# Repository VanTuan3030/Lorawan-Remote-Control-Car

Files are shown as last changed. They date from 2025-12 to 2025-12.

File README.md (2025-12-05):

# Hand Gesture Controlled Car via LoRaWAN (STM32 + MPU6050)

This project builds a remote-controlled robot car system using **Hand Gesture Control**, powered by **LoRa (Long Range)** wireless communication technology. The system allows for stable vehicle control over long distances with excellent obstacle penetration, significantly outperforming traditional RF or Bluetooth solutions.

## 📡 LoRa Technology - Project Highlight

This is the core feature that sets this project apart. Instead of using standard radio waves, the system utilizes the **LoRa Ra-02 (SX1278)** module operating at **433MHz**.

### Why LoRa?
* **Superior Range:** Capable of transmitting signals from several hundred meters to kilometers (in ideal conditions), solving the signal loss issue when the car travels far away.
* **High Interference Immunity:** Uses **CSS (Chirp Spread Spectrum)** modulation technique, ensuring signals are not attenuated or interfered with by other electronic devices.
* **Obstacle Penetration:** The 433MHz LoRa signal has a long wavelength, allowing for vehicle control even when obstructed by walls or large objects.

### Communication Protocol
The system operates on a **Point-to-Point (P2P)** model:
1.  **Data Acquisition:** The STM32 microcontroller at the Transmitter reads tilt angles (Roll, Pitch) from the MPU6050 sensor.
2.  **Packetizing:** Data is packed into a `Struct` to ensure integrity.
3.  **Modulation & Transmission:** The SX1278 module modulates this packet into LoRa waves and transmits it.
4.  **Decoding & Execution:** The Receiver captures the waves, decodes the packet back into motor control signals.

## 🚀 Key Features

* **Gesture Control:**
    * 👋 **Tilt Forward:** Move Forward.
    * 👋 **Tilt Backward:** Move Backward.
    * 👋 **Tilt Left/Right:** Turn Left/Right.
    * 👋 **Keep Level:** Stop.
* **Real-time Processing:** Ultra-fast response speed thanks to the STM32F103 microcontroller (32-bit ARM Cortex-M3).
* **Powerful & Flexible:** The car uses 4 DC motors with an L298N Driver, enabling versatile multi-directional movement.

## 🛠️ Hardware Requirements

### 1. Transmitter (Handheld)
* **Microcontroller:** STM32F103C8T6 (Blue Pill).
* **Sensor:** MPU6050 (6-axis Accelerometer & Gyroscope).
* **Communication:** LoRa Ra-02 Module (SX1278) + 433MHz Antenna (Spring/External).
* **Power:** 3.7V Li-ion Battery or 9V Battery.

### 2. Receiver (Car)
* **Microcontroller:** STM32F103C8T6 (Blue Pill).
* **Communication:** LoRa Ra-02 Module (SX1278).
* **Motors:** L298N Driver + 4 DC Geared Motors + Robot Chassis.
* **Power:** High-capacity Rechargeable Battery (e.g., 2x 18650 cells in series ~7.4V).

## 🔌 Pinout Diagram

Communication between STM32 and LoRa SX1278 uses the **SPI** standard.

### Transmitter Unit

| Device | STM32 Pin | Function |
| :--- | :--- | :--- |
| **LoRa Ra-02 (NSS)** | PA4 | Chip Select (CS) |
| **LoRa Ra-02 (SCK)** | PA5 | SPI Clock |
| **LoRa Ra-02 (MISO)**| PA6 | SPI Data In |
| **LoRa Ra-02 (MOSI)**| PA7 | SPI Data Out |
| **LoRa Ra-02 (RST)** | PB0 | Reset |
| **LoRa Ra-02 (DIO0)**| PB1 | Interrupt (Tx Done) |
| **MPU6050 (SCL)** | PB6 | I2C Clock |
| **MPU6050 (SDA)** | PB7 | I2C Data |

### Receiver Unit

| Device | STM32 Pin | Function |
| :--- | :--- | :--- |
| **LoRa Ra-02** | PA4, PA5, PA6, PA7 | SPI Connection (Same as Transmitter) |
| **L298N (IN1)** | PA0 | Left Motor (+) |
| **L298N (IN2)** | PA1 | Left Motor (-) |
| **L298N (IN3)** | PA2 | Right Motor (+) |
| **L298N (IN4)** | PA3 | Right Motor (-) |

## 💻 Installation and Usage

1.  **Software & Libraries:**
    * IDE: **Keil C V5** or **STM32CubeIDE**.
    * Configuration: **STM32CubeMX** (Configure SPI for LoRa, I2C for MPU6050).
    * Libraries: Import driver libraries for `SX1278` and `MPU6050`.

2.  **Flashing Firmware:**
    * Connect the ST-Link V2 programmer.
    * Upload `Transmitter.hex` code to the handheld circuit.
    * Upload `Receiver.hex` code to the car circuit.

3.  **Operation:**
    * Turn on the car power first, then the handheld controller.
    * Wait 1-2 seconds for the LoRa modules to initialize and synchronize frequencies.
    * Tilt your hand and observe the car's movement.

## 👤 Authors

* **Student Team:** Vo Van Tuan - 6251020094
* **Instructor:** Dr. Le Tien Loc
* **Class:** Industrial Electronics & Informatics K62
* **University:** University of Transport and Communications - HCMC Campus

---
*Project for the Course Final Report - IoT & LoRa Applications.*

https://github.com/user-attachments/assets/69dc1bef-388b-4bd6-928f-9bf30ec7da8c

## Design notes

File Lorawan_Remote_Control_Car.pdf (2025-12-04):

TRƯỜNG ĐẠI HỌC GIAO THÔNG VẬN TẢI

PHÂN HIỆU TẠI THÀNH PHỐ HỒ CHÍ MINH

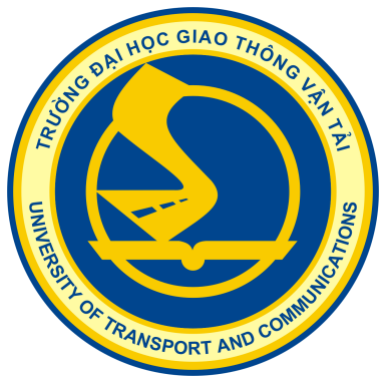
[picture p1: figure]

### BÁO CÁO TỔNG KẾT

## ĐIỀU KHIỂN XE BẰNG MPU6050 THÔNG QUA

## LORA

Sinh viên thực hiện | Ngô Huỳnh Quốc Huy | Mssv: 6251020057
| Võ Văn Tuấn | Mssv: 6251020094
| Hà Nhật Chương | Mssv: 6251020037

Lớp: Điện tử tin học công nghiệp K62

Người hướng dẫn: TS. Lê Tiến Lộc

TPHCM, 2025

TRƯỜNG ĐẠI HỌC GIAO THÔNG VẬN TẢI

PHÂN HIỆU TẠI THÀNH PHỐ HỒ CHÍ MINH

### BÁO CÁO TỔNG KẾT

## ĐIỀU KHIỂN XE BẰNG MPU6050 THÔNG QUA

## LORA

Sinh viên thực hiện | Ngô Huỳnh Quốc Huy | Mssv: 6251020057
| Võ Văn Tuấn | Mssv: 6251020094
| Hà Nhật Chương | Mssv: 6251020037

Lớp: Điện tử tin học công nghiệp K62

Người hướng dẫn: TS. Lê Tiến Lộc

TPHCM, 2025

MỤC LỤC

DANH MỤC HÌNH ẢNH

DANH MỤC BẢNG

KÍ TỰ VIẾT TẮT

Viết tắt | Diễn giải
ADC | Analog to Digital Converter (Bộ chuyển đổi tương tự – số)
DOF | Degree of Freedom (Bậc tự do)
DMP | Digital Motion Processor (Bộ xử lý chuyển động số)
HAL | Hardware Abstraction Layer (Lớp trừu tượng phần cứng)
I2C | Inter-Integrated Circuit (Chuẩn giao tiếp nối tiếp)
LoRa | Long Range (Công nghệ truyền thông tầm xa)
MPU6050 | Tên cảm biến tích hợp gia tốc kế & con quay hồi chuyển
NSS | Network Select Slave (Chân chọn chip trong giao tiếp SPI)
PWM | Pulse Width Modulation (Điều chế độ rộng xung)
SPI | Serial Peripheral Interface (Giao tiếp ngoại vi nối tiếp)
STM32 | Dòng vi điều khiển 32-bit của STMicroelectronics
UART | Universal Asynchronous Receiver Transmitter (Truyền nhận không đồng bộ phổ thông)

CHƯƠNG 1: GIỚI THIỆU ĐỀ TÀI

1.1. Lý do chọn đề tài.

Nhu cầu thị trường:

Hiện nay, các hệ thống điều khiển phương tiện, robot hoặc thiết bị từ xa phần lớn vẫn sử dụng tay điều khiển (remote) hoặc điện thoại thông minh kết nối qua Bluetooth hoặc WiFi. Tuy nhiên, các công nghệ này có phạm vi hoạt động hạn chế và dễ bị ảnh hưởng bởi vật cản, tín hiệu nhiễu hoặc mất kết nối trong môi trường rộng lớn, đặc biệt ở các khu vực không có mạng internet ổn định. Điều này gây ra nhiều bất tiện cho người sử dụng cũng như hạn chế khả năng mở rộng ứng dụng trong thực tế.

Tiềm năng ứng dụng rộng rãi:

Việc điều khiển thiết bị từ xa bằng cách sử dụng cảm biến chuyển động (MPU6050) kết hợp với công nghệ truyền thông tầm xa LoRa mở ra hướng ứng dụng rộng rãi cho nhiều lĩnh vực như: xe điều khiển trong nông nghiệp, robot cứu hộ, xe tự hành, hoặc các thiết bị vận chuyển trong nhà kho, nhà máy. Giải pháp này cho phép người dùng điều khiển thiết bị một cách trực quan bằng các cử chỉ tay mà không cần dây dẫn hay mạng internet, đồng thời duy trì kết nối ổn định ở khoảng cách xa.

Ứng dụng công nghệ tiên tiến:

Đề tài ứng dụng cảm biến MPU6050 – một module tích hợp con quay hồi chuyển và gia tốc kế – để nhận biết chuyển động của tay người điều khiển. Dữ liệu từ cảm biến sẽ được xử lý và truyền không dây bằng công nghệ LoRa, vốn nổi bật với khả năng truyền xa (lên đến hàng km) và tiêu thụ năng lượng thấp. Hệ thống có thể hoạt động hiệu quả trong môi trường mở, độc lập với hạ tầng mạng hiện có, đồng thời dễ dàng triển khai thực tế.

Chi phí triển khai hợp lý:

Các module MPU6050 và LoRa hiện nay có giá thành thấp, phổ biến trên thị trường và dễ tiếp cận đối với sinh viên, kỹ sư hoặc cá nhân nghiên cứu độc lập. Điều này cho phép triển khai hệ thống điều khiển thông minh với chi phí thấp hơn nhiều so với các giải pháp thương mại, đồng thời dễ dàng mở rộng và tùy chỉnh theo nhu cầu sử dụng. Đề tài mang lại một lựa chọn tiết kiệm, linh hoạt và phù hợp với xu hướng phát triển thiết bị điều khiển không dây hiện đại.

### 1.2. Mục tiêu đề tài

Xây dựng hệ thống điều khiển xe từ xa bằng cử chỉ tay thông qua cảm biến MPU6050, truyền tín hiệu không dây bằng công nghệ LoRa với chi phí thấp, dễ triển khai và không phụ thuộc vào mạng internet.

Nhận diện chính xác chuyển động tay (nghiêng, xoay) để điều khiển các hướng di chuyển của xe (tiến, lùi, trái, phải), đảm bảo độ nhạy và độ trễ thấp trong quá trình điều khiển thực tế.

Tăng tính linh hoạt và tự động hóa, giúp người dùng điều khiển xe từ khoảng cách xa (lên đến vài trăm mét đến vài km trong điều kiện lý tưởng), phù hợp cho các ứng dụng trong nông nghiệp, môi trường đặc biệt hoặc robot địa hình.

CHƯƠNG 2: CƠ SỞ LÝ THUYẾT

### 2.1. Khái niệm về hệ thống nhúng

Hệ thống nhúng (embedded system) là một thuật ngữ để chỉ một hệ thống có khả năng tự trị được nhúng vào trong một môi trường hay hệ thống mẹ. Đó là các hệ thống tích hợp cả phần cứng và phần mềm phục vụ các bài toán chuyên dụng trong nhiều lĩnh vực công nghiệp, tự động hoá điều khiển, quan trắc và truyền tin. Đặc điểm của các hệ thống nhúng là hoạt động ổn định và có tính năng tự động hoá cao.

Hệ thống nhúng thường được thiết kế để thực hiện một chức năng chuyên biệt nào đó. Khác với các máy tính (https://vi.wikipedia.org/wiki/M%C3%A1y_t%C3%ADnh) đa chức năng, chẳng hạn như máy tính cá nhân, (https://vi.wikipedia.org/wiki/M%C3%A1y_t%C3%ADnh_c%C3%A1_nh%C3%A2n) một hệ thống nhúng chỉ thực hiện một hoặc một vài chức năng nhất định, thường đi kèm với những yêu cầu cụ thể và bao gồm một số thiết bị máy móc và phần cứng chuyên dụng mà ta không tìm thấy trong một máy tính đa năng nói chung. Vì hệ thống chỉ được xây dựng cho một số nhiệm vụ nhất định nên các nhà thiết kế có thể tối ưu hóa nó nhằm giảm thiểu kích thước và chi phí sản xuất. Các hệ thống nhúng thường được sản xuất hàng loạt với số lượng lớn. Hệ thống nhúng rất đa dạng, phong phú về chủng loại. Đó có thể là những thiết bị cầm tay nhỏ gọn như đồng hồ kĩ thuật số và máy chơi nhạc MP3, hoặc những sản phẩm lớn như đèn giao thông, bộ kiểm soát trong nhà máy hoặc hệ thống kiểm soát các máy năng lượng hạt nhân. Xét về độ phức tạp, hệ thống nhúng có thể rất đơn giản với một vi điều khiển (https://vi.wikipedia.org/wiki/Vi_%C4%91i%E1%BB%81u_khi%E1%BB%83n) hoặc rất phức tạp với nhiều đơn vị, các thiết bị ngoại vi và mạng lưới được nằm gọn trong một lớp vỏ máy lớn.

Các thiết bị PDA hoặc máy tính cầm tay cũng có một số đặc điểm tương tự với hệ thống nhúng như các hệ điều hành hoặc vi xử lý điều khiển chúng nhưng các thiết bị này không phải là hệ thống nhúng thật sự bởi chúng là các thiết bị đa năng, cho phép sử dụng nhiều ứng dụng và kết nối đến nhiều thiết bị ngoại vi.

Bên cạnh đó, xu hướng hiện nay đang hướng đến việc phát triển các hệ thống nhúng thông minh, có khả năng kết nối Internet (IoT – Internet of Things) và xử lý dữ liệu ngay tại thiết bị mà không cần phụ thuộc vào máy chủ trung tâm. Việc tích hợp trí tuệ nhân tạo (AI) vào hệ thống nhúng cũng đang được nghiên cứu và ứng dụng mạnh mẽ, mở ra nhiều tiềm năng mới trong lĩnh vực tự động hóa và điều khiển thông minh.

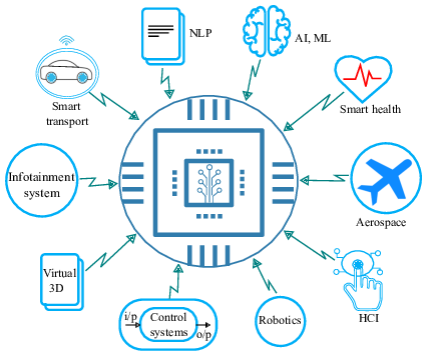
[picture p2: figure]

Hình 2.1: Hệ thống nhúng

### 2.2. Tín hiệu cảm biến và xử lý tín hiệu

Trong một hệ thống đo lường, cảm biến là thành phần đầu vào có nhiệm vụ chuyển đổi các đại lượng vật lý cần đo (chẳng hạn như chuyển động, áp suất, nhiệt độ, ánh sáng, từ trường…) thành tín hiệu điện. Đây là bước quan trọng đầu tiên để biến thông tin thực tế thành dữ liệu có thể phân tích và xử lý trong môi trường số.

Tín hiệu do cảm biến tạo ra thường thuộc một trong hai dạng chính:

Tín hiệu tương tự (analog): Là tín hiệu biến thiên liên tục theo thời gian, biểu hiện qua điện áp hoặc dòng điện thay đổi theo giá trị đo được. Loại tín hiệu này yêu cầu sử dụng bộ chuyển đổi tương tự – số (ADC) để đưa vào xử lý trên hệ thống vi điều khiển.

Tín hiệu số (digital): Là tín hiệu có dạng rời rạc, thường biểu diễn bằng hai mức logic (cao/thấp, 1/0). Loại tín hiệu này có thể được đọc trực tiếp bởi các chân vào số của vi điều khiển, và được xử lý dễ dàng hơn so với tín hiệu tương tự.

Việc xử lý tín hiệu cảm biến trong hệ thống đo lường thường bao gồm các bước:

Xử lý: Bao gồm khuếch đại tín hiệu yếu, lọc nhiễu điện, ổn định mức tín hiệu đầu vào.

Chuyển đổi tín hiệu: Nếu là tín hiệu analog thì cần chuyển đổi sang dạng số; nếu là tín hiệu số thì có thể đọc và xử lý trực tiếp.

Trích xuất thông tin: Là bước phân tích dữ liệu nhận được để rút ra giá trị đo có ý nghĩa, như tốc độ, vị trí...

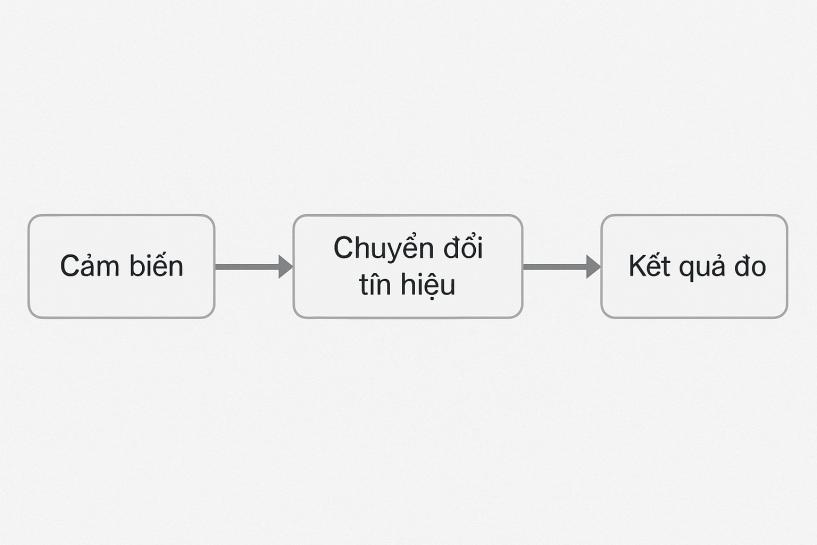
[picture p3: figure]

Hình 2.2: Mô hình cảm biến

### 2.3. Tổng quan về hệ thống nhúng trong đo lường

Một hệ thống đo lường sử dụng nền tảng hệ nhúng thường hoạt động theo một chu trình khép kín và liên tục, đảm bảo thu thập và xử lý dữ liệu một cách hiệu quả và đáng tin cậy. Quy trình cơ bản có thể mô tả qua các bước sau:

Giai đoạn thu nhận dữ liệu đầu vào: Các cảm biến chuyên dụng sẽ ghi nhận các đại lượng vật lý như chuyển động, áp suất, ánh sáng, nhiệt độ, độ ẩm, tốc độ dòng chảy,... tùy theo yêu cầu của ứng dụng. Mỗi loại cảm biến thường cho ra tín hiệu điện áp, dòng điện hoặc xung số tương ứng với giá trị của đại lượng đo được.

Giai đoạn chuyển đổi và đưa vào hệ thống: Tín hiệu đầu ra của cảm biến sẽ được đưa vào hệ thống nhúng thông qua các chân analog hoặc digital trên vi điều khiển. Trường hợp tín hiệu là analog, hệ thống sẽ sử dụng bộ chuyển đổi ADC (Analog to Digital Converter) để biến đổi thành tín hiệu số phục vụ cho xử lý.

Xử lý tín hiệu và tính toán: Vi điều khiển trong hệ thống nhúng sẽ nhận dữ liệu và thực hiện các thuật toán xử lý: lọc nhiễu, tính trung bình, phân tích ngưỡng, hoặc các thuật toán điều khiển như PID. Đây là khâu quan trọng giúp đảm bảo kết quả đo chính xác, ổn định và phù hợp với yêu cầu thực tế.

Giai đoạn xuất dữ liệu: Sau khi xử lý, kết quả có thể được hiển thị trực tiếp trên màn hình LCD/OLED, hoặc được gửi đi thông qua giao tiếp UART, I2C, SPI hoặc Wi-Fi/Bluetooth. Ngoài ra, hệ thống cũng có thể ghi log vào bộ nhớ trong, thẻ SD hoặc gửi lên server/cloud/Firebase để lưu trữ và phân tích từ xa.

Tổng quát, mô hình hoạt động có thể biểu diễn như sau:

Cảm biến → Vi điều khiển → Xử lý tín hiệu → Hiển thị / Giao tiếp / Lưu trữ

Trong các ứng dụng hiện đại, hệ thống nhúng còn có thể mở rộng thêm các chức năng như gửi cảnh báo khi vượt ngưỡng, kích hoạt relay điều khiển thiết bị, hoặc đồng bộ dữ liệu thời gian thực với hệ thống giám sát trung tâm. Điều này giúp hệ nhúng không chỉ là công cụ đo lường đơn thuần mà còn đóng vai trò như một phần tử quyết định trong hệ thống điều khiển tự động và thông minh hóa quy trình.

CHƯƠNG 3: GIỚI THIỆU LINH KIỆN SỬ DỤNG

### 3.1. Vi điều khiển STM32F103C8T6

### 3.1.1. Giới thiệu chung

STM32F103C8T6 là vi điều khiển thuộc dòng STM32 của STMicroelectronics, sử dụng lõi ARM Cortex-M3 với tốc độ xử lý lên đến 72 MHz. Đây là một trong những dòng vi điều khiển phổ biến nhờ khả năng xử lý mạnh, tiêu thụ năng lượng thấp, giá thành rẻ và được hỗ trợ bởi cộng đồng phát triển rộng lớn.

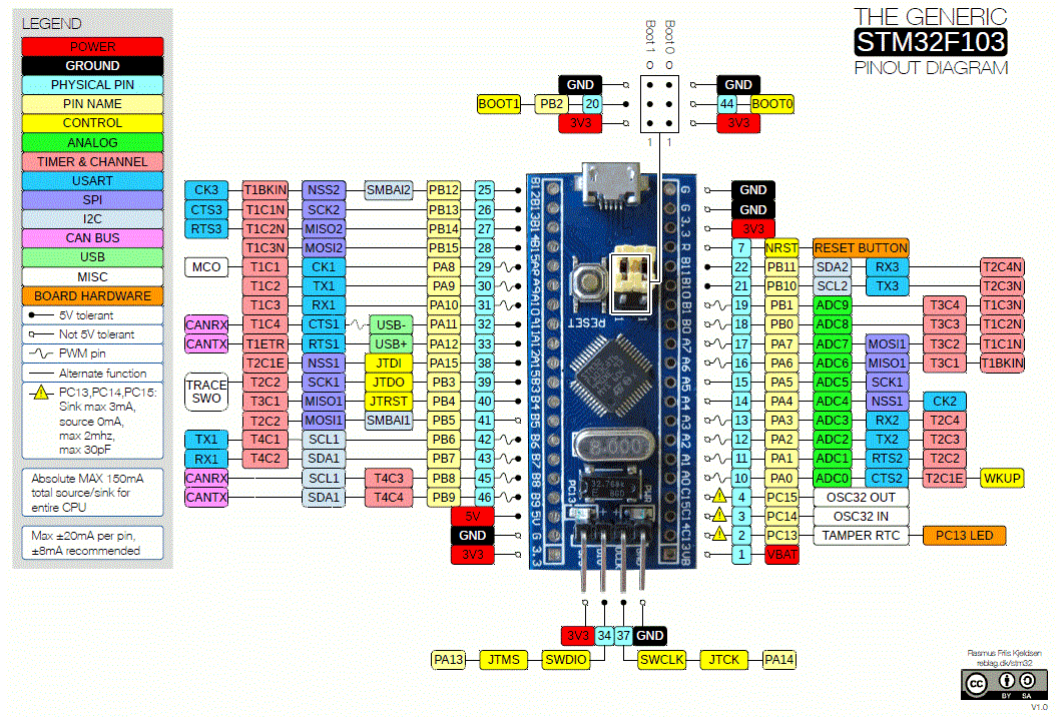
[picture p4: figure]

Hinh 3.1: tổng quan stm32f103c8

### 3.1.2. Thông số kỹ thuật chính

Lõi xử lý: ARM Cortex-M3, 32-bit, 72 MHz

Bộ nhớ: 64 KB Flash, 20 KB SRAM

Số chân I/O: 37 (đa chức năng)

Giao tiếp: UART, I2C, SPI, PWM, ADC,...

Điện áp hoạt động: 2.0V – 3.6V

Tích hợp đồng hồ RTC, bộ định thời (Timer), Watchdog,...

### 3.1.3. Vai trò trong hệ thống

STM32F103C8T6 là bộ vi điều khiển lõi ARM Cortex-M3 được thiết kế để đáp ứng các yêu cầu xử lý đa nhiệm trong các ứng dụng nhúng. Với tốc độ xử lý lên đến 72 MHz cùng bộ ngoại vi phong phú như UART, SPI, I2C, ADC, PWM,... STM32 cho phép kết nối với nhiều loại cảm biến và module truyền thông. Ngoài ra, nó hỗ trợ chế độ tiết kiệm năng lượng và khả năng xử lý ngắt linh hoạt, rất phù hợp cho các hệ thống yêu cầu phản hồi nhanh và ổn định.

Trong hệ thống điều khiển xe bằng cử chỉ, STM32F103C8 đóng vai trò là trung tâm xử lý chính:

Giao tiếp với cảm biến MPU6050 thông qua giao thức I2C để thu thập dữ liệu chuyển động (góc nghiêng, vận tốc quay).

Xử lý tín hiệu cảm biến, áp dụng các thuật toán lọc (như low-pass filter, Kalman filter) để loại bỏ nhiễu và ổn định dữ liệu đầu vào.

Phân tích dữ liệu chuyển động để xác định hành động điều khiển tương ứng (ví dụ: nghiêng tay về phía trước tương ứng với lệnh "tiến").

Truyền lệnh điều khiển sang module LoRa, sử dụng giao thức SPI, để gửi dữ liệu không dây đến phần nhận tín hiệu trên xe.

Nhờ khả năng xử lý nhanh, hoạt động ổn định và tài nguyên phần cứng đa dạng, STM32 là lựa chọn lý tưởng cho các hệ thống điều khiển thực thời có yêu cầu về độ tin cậy và độ trễ thấp.

### 3.2. Cảm biến MPU6050

### 3.2.1. Giới thiệu chung

MPU6050 là cảm biến tích hợp 3 trục gia tốc kế và 3 trục con quay hồi chuyển, cho phép đo được gia tốc tuyến tính và tốc độ quay quanh các trục XYZ. Module này rất phổ biến trong các ứng dụng nhận dạng chuyển động, cân bằng robot, điều khiển bằng cử chỉ...

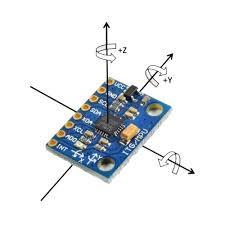
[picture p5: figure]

Hinh 3.2: tổng quan mpu6050

### 3.2.2. Thông số kỹ thuật chính

Gia tốc kế: ±2g, ±4g, ±8g, ±16g

Con quay hồi chuyển: ±250, ±500, ±1000, ±2000°/s

Giao tiếp: I2C (địa chỉ mặc định 0x68)

Tích hợp DMP (Digital Motion Processor)

Điện áp hoạt động: 3.3V – 5V

### 3.2.3. Vai trò trong hệ thống

MPU6050 là cảm biến tích hợp 6 bậc tự do (6 DOF), bao gồm:

Gia tốc kế 3 trục (Accelerometer): đo gia tốc tuyến tính dọc theo các trục X, Y, Z (đơn vị: m/s² hoặc g).

Con quay hồi chuyển 3 trục (Gyroscope): đo tốc độ quay quanh các trục X, Y, Z (đơn vị: độ/giây).

MPU6050 có thể kết hợp dữ liệu từ cả hai loại cảm biến để tính toán góc nghiêng (pitch, roll, yaw) của thiết bị. Với khả năng giao tiếp qua I2C, cảm biến dễ dàng kết nối với các vi điều khiển để truyền dữ liệu thời gian thực.

Trong đề tài này, MPU6050 được gắn vào tay người điều khiển. Dựa trên dữ liệu từ cảm biến:

Khi người dùng nghiêng tay theo hướng nhất định, hệ thống sẽ ghi nhận được sự thay đổi góc nghiêng hoặc vận tốc quay.

Dữ liệu này được phân tích để xác định hành vi điều khiển: nghiêng trái → rẽ trái, nghiêng phải → rẽ phải, nghiêng về trước → đi tới, nghiêng lùi → đi lui.

MPU6050 đóng vai trò như một bộ điều khiển chuyển động tự nhiên, thay thế cho các thiết bị điều khiển truyền thống như joystick hay nút bấm.

Tuy nhiên, do đặc điểm nhạy cảm với dao động nhỏ và nhiễu từ môi trường, cần phải có bộ lọc tín hiệu và hiệu chỉnh trong phần mềm để đảm bảo tính ổn định và chính xác của tín hiệu điều khiển.

### 3.3. Module truyền thông LoRa

### 3.3.1. Giới thiệu chung

LoRa là công nghệ truyền thông không dây tầm xa, tiêu thụ năng lượng thấp, sử dụng kỹ thuật điều chế LoRa (Long Range). Module Ra-02 hoặc SX1278 là một trong những phiên bản phổ biến, hoạt động ở tần số 433 MHz hoặc 868/915 MHz tùy theo khu vực.

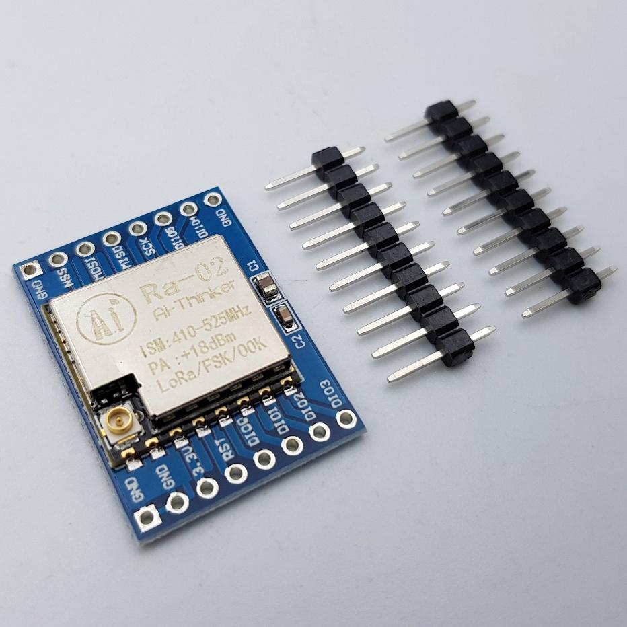
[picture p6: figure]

Hinh 3.3: tổng quan lora

### 3.3.2. Thông số kỹ thuật chính

Tần số hoạt động: 433 MHz (hoặc 868/915 MHz)

Khoảng cách truyền: lên đến 2–5 km (môi trường mở)

Giao tiếp: SPI

Công suất phát: +20 dBm

Tốc độ truyền: 0.018 – 37.5 kbps

Điện áp: 1.8V – 3.7V (thường dùng 3.3V)

### 3.3.3. Vai trò trong hệ thống

LoRa (Long Range) là công nghệ truyền thông không dây sử dụng kỹ thuật điều chế dải tần rộng (spread spectrum modulation), giúp truyền tín hiệu ở khoảng cách xa với công suất thấp. LoRa hoạt động tốt trong môi trường có vật cản hoặc khu vực nông thôn – nơi tín hiệu WiFi hoặc Bluetooth thường bị hạn chế.

Các module như Ra-02 hoặc SX1278 sử dụng giao thức SPI để giao tiếp với vi điều khiển, có khả năng truyền dữ liệu với khoảng cách lên đến 2–5 km trong điều kiện lý tưởng.

Trong hệ thống điều khiển xe:

LoRa được sử dụng để truyền tín hiệu điều khiển từ bộ tay cầm (người điều khiển) đến xe. Tín hiệu này chứa thông tin đã được xử lý từ MPU6050, như hướng di chuyển và trạng thái hành động.

Nhờ khả năng truyền xa và chống nhiễu tốt, LoRa cho phép người dùng điều khiển xe ở khoảng cách lớn mà không cần đến mạng internet.

Hệ thống hoạt động ở tần số 433 MHz hoặc 868 MHz, với tốc độ truyền vừa phải nhưng ổn định và tiết kiệm năng lượng, phù hợp với các ứng dụng điều khiển đơn giản nhưng yêu cầu truyền xa và đáng tin cậy.

LoRa không thích hợp cho truyền dữ liệu lớn, nhưng rất phù hợp trong ứng dụng điều khiển như đề tài này, nơi chỉ cần gửi các gói dữ liệu nhỏ nhưng thường xuyên và ổn định.

CHƯƠNG 4: THIẾT KẾ HỆ THỐNG ĐIỀU KHIỂN

4.1, kiến trúc tổng thể của hệ thống

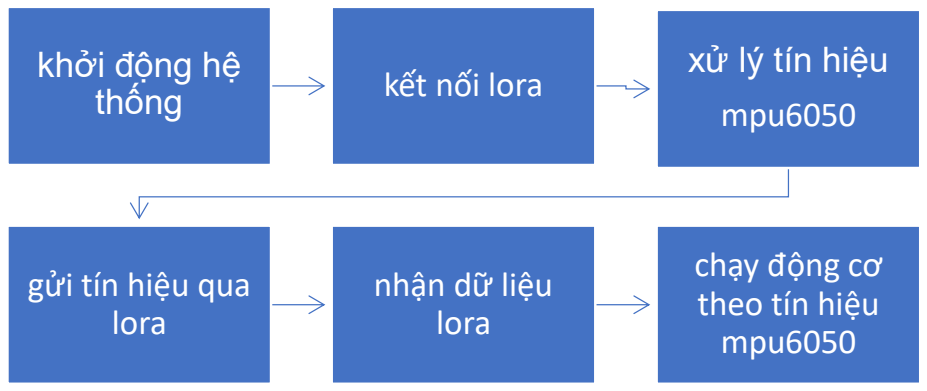
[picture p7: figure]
khởi động hệ; thống; kết nối lora; xử lý tín hiệu; mpu6050; gửi tín hiệu qua lora; nhận dữ liệu lora; chạy động cơ theo tín hiệu mpu6050

Bảng 4.1 lưu đồ thuật toán

Khởi động hệ thống

Hệ thống bắt đầu hoạt động khi được cấp nguồn. Vi điều khiển (STM32F103C8) tiến hành khởi tạo các thành phần phần cứng: cảm biến MPU6050, module LoRa, các chân I/O.

Kết nối LoRa

Hai module LoRa (phát và thu) được cấu hình để sẵn sàng truyền và nhận dữ liệu. Đây là bước thiết lập thông số truyền (tần số, địa chỉ, tốc độ baud...) giữa hai bên.

Xử lý tín hiệu MPU6050

Cảm biến MPU6050 gửi dữ liệu thô (góc nghiêng, gia tốc, tốc độ quay) đến vi điều khiển thông qua giao tiếp I2C. STM32 xử lý dữ liệu này (lọc nhiễu, phân tích) để xác định hướng điều khiển tương ứng (tiến, lùi, rẽ trái, rẽ phải...).

Gửi tín hiệu qua LoRa

STM32 mã hóa thông tin điều khiển (dưới dạng gói lệnh) và gửi qua module LoRa để truyền không dây đến mạch thu gắn trên xe.

Nhận dữ liệu LoRa

Mạch thu nhận gói dữ liệu từ mạch phát thông qua module LoRa. Dữ liệu sau đó được gửi đến STM32 để xử lý tiếp.

Chạy động cơ theo tín hiệu MPU6050

STM32 ở mạch thu sẽ dịch gói lệnh điều khiển thành tín hiệu logic điều khiển module L298 để quay động cơ theo yêu cầu. Xe sẽ di chuyển đúng với hướng tay người điều khiển.

4.2, Phần cứng hệ thống phát

4.2.1.Sơ đồ mạch điện

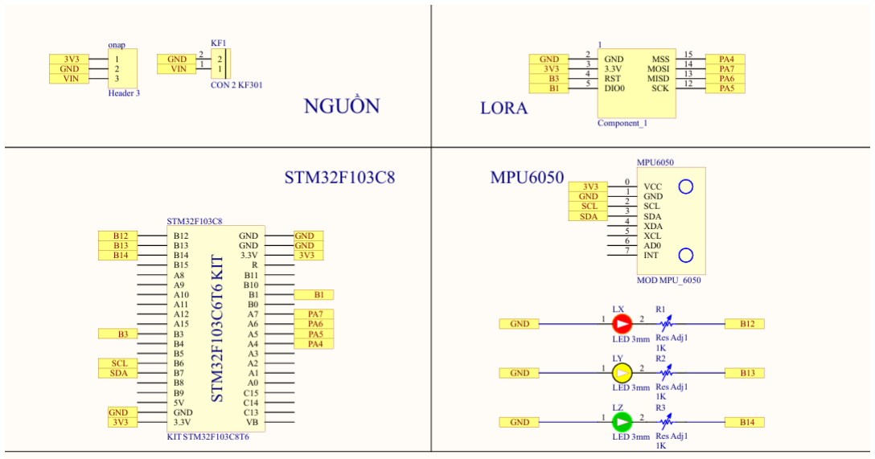
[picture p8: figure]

Hinh 4.1: sơ đồ mạch phát

Mạch phát là phần trung tâm trong hệ thống điều khiển xe từ xa bằng cử chỉ tay. Mạch này được gắn lên tay người dùng và có nhiệm vụ thu nhận chuyển động từ cảm biến MPU6050, xử lý dữ liệu qua vi điều khiển STM32F103C8, sau đó truyền tín hiệu điều khiển đến mạch thu trên xe thông qua module LoRa. Toàn bộ hệ thống được cấp nguồn bằng điện áp 3.3V từ bộ nguồn ngoài.

### 4.2.1.1. Khối nguồn

Khối nguồn có nhiệm vụ cung cấp điện áp ổn định 3.3V cho toàn bộ hệ thống. Nguồn được cấp qua jack CON2 KF301 với hai đầu vào: VIN và GND. Điện áp được điều chỉnh phù hợp cho các linh kiện như STM32, MPU6050 và module LoRa. Khối này đảm bảo hệ thống hoạt động ổn định và an toàn về điện.

### 4.2.1.2. Vi điều khiển STM32F103C8

Vi điều khiển STM32F103C8 đóng vai trò là bộ xử lý trung tâm của hệ thống mạch phát. Nó đảm nhiệm các chức năng sau:

Giao tiếp với cảm biến MPU6050 thông qua chuẩn I2C (chân PB6 – SCL và PB7 – SDA).

Giao tiếp với module LoRa thông qua chuẩn SPI (chân PA4 đến PA7).

Phân tích dữ liệu chuyển động, nhận biết cử chỉ tay điều khiển và chuyển đổi thành tín hiệu điều khiển cụ thể cho xe.

Xuất tín hiệu điều khiển LED thông báo trạng thái chuyển động qua các chân PB12, PB13, PB14 (ứng với trục X, Y, Z).

Vi điều khiển được cấp nguồn 3.3V và có các chân GND được nối về mass chung, đảm bảo tính ổn định cho toàn hệ thống.

### 4.2.1.3. Cảm biến MPU6050

Cảm biến MPU6050 có chức năng ghi nhận dữ liệu chuyển động tay người điều khiển. Cảm biến tích hợp gia tốc kế 3 trục và con quay hồi chuyển 3 trục, cho phép đo được góc nghiêng và tốc độ xoay của tay theo thời gian thực.

Trong mạch phát, MPU6050 được kết nối với STM32 thông qua giao tiếp I2C:

SCL nối với chân PB6.

SDA nối với chân PB7.

Nguồn 3.3V cấp vào chân VCC và GND của cảm biến. Dữ liệu chuyển động thu được từ MPU6050 sẽ được vi điều khiển xử lý để tạo ra lệnh điều khiển thích hợp cho xe.

### 4.2.1.4. Module truyền thông LoRa

Module LoRa (thường dùng SX1278 hoặc Ra-02) là thành phần đảm nhận việc truyền tín hiệu không dây từ bộ phát đến bộ thu gắn trên xe. Module này hoạt động với tần số 433 MHz và được kết nối với STM32 thông qua giao tiếp SPI, cụ thể:

MOSI (Master Out Slave In): PA7.

MISO (Master In Slave Out): PA6.

SCK (Serial Clock): PA5.

NSS (Chip Select): PA4.

Module nhận dữ liệu điều khiển từ STM32 và phát sóng RF đến module LoRa còn lại trong hệ thống. Nhờ khả năng truyền xa và tiêu thụ năng lượng thấp, LoRa giúp hệ thống hoạt động ổn định trong khoảng cách vài trăm mét đến vài km tùy điều kiện môi trường.

### 4.2.1.5. Hệ thống LED hiển thị

Ba đèn LED (màu đỏ, vàng, xanh) được sử dụng để hiển thị trạng thái hoạt động của hệ thống theo ba trục chuyển động:

LED đỏ (trục X): nối với PB12.

LED vàng (trục Y): nối với PB13.

LED xanh (trục Z): nối với PB14.

Mỗi LED được mắc nối tiếp với điện trở hạn dòng 1KΩ để bảo vệ linh kiện khỏi hư hỏng do quá dòng. Các LED này giúp người dùng dễ dàng nhận biết hướng chuyển động đang được ghi nhận, đồng thời hỗ trợ kiểm tra nhanh hệ thống trong quá trình thử nghiệm.

4.3, Phần cứng hệ thống thu

4.3.1.Sơ đồ mạch điện

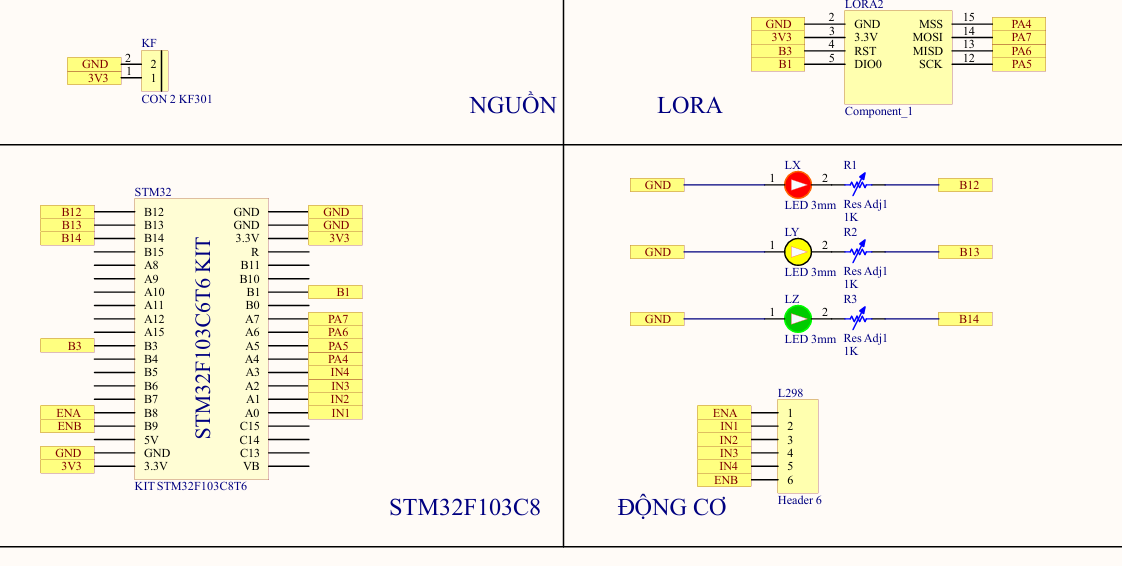
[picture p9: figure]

Hinh 4.2: sơ đồ mạch thu

Mạch thu có nhiệm vụ nhận tín hiệu điều khiển được truyền từ mạch phát thông qua module LoRa, sau đó giải mã tín hiệu và điều khiển động cơ theo các lệnh nhận được.

Mạch thu được gắn trực tiếp trên xe điều khiển, bao gồm các khối chức năng: khối nguồn, vi điều khiển STM32F103C8, module LoRa, bộ điều khiển động cơ (L298), và hệ thống LED hiển thị.

### 4.3.1.1. Khối nguồn

Khối nguồn sử dụng điện áp 3.3V được cấp từ ngoài qua jack CON2 KF301. Nguồn này được dùng để cấp điện cho vi điều khiển STM32, module LoRa và các phần tử điều khiển khác trong hệ thống. Mass (GND) được nối chung toàn mạch để đảm bảo ổn định điện áp và tránh nhiễu.

### 4.3.1.2. Vi điều khiển STM32F103C8

STM32F103C8 là bộ xử lý trung tâm của mạch thu, thực hiện các chức năng chính sau:

Giao tiếp SPI với module LoRa để nhận dữ liệu điều khiển (thông qua các chân PA4– PA7).

Phân tích và giải mã tín hiệu nhận được để xác định hướng di chuyển của xe (tiến, lùi, rẽ trái, rẽ phải).

Xuất tín hiệu điều khiển động cơ thông qua các chân PA0–PA3 (kết nối với L298).

Điều khiển LED hiển thị trạng thái hoạt động qua các chân PB12, PB13, PB14.

STM32 được cấp nguồn 3.3V từ khối nguồn chung và sử dụng các chân GND để nối mass.

### 4.3.1.3. Module truyền thông LoRa

Module LoRa được sử dụng để nhận dữ liệu điều khiển không dây từ bộ phát. Cấu hình giao tiếp giống như trên mạch phát:

MOSI → PA7

MISO → PA6

SCK → PA5

NSS (CS) → PA4

Module sẽ tiếp nhận lệnh điều khiển được mã hóa từ mạch phát và gửi vào STM32 để xử lý.

### 4.3.1.4. Mạch điều khiển động cơ (L298)

Module L298 là bộ cầu H điều khiển 2 động cơ DC độc lập. Trong mạch thu, nó được điều khiển bởi STM32 thông qua các chân:

IN1 → PA0, IN2 → PA1

IN3 → PA2, IN4 → PA3

ENA và ENB có thể kết nối với nguồn hoặc điều khiển qua PWM (tùy cấu hình phần mềm)

Dựa vào tín hiệu điều khiển từ STM32, L298 sẽ kích hoạt động cơ quay theo hướng mong muốn (tiến, lùi, rẽ). Đây là thành phần chính để chuyển lệnh điều khiển từ cử chỉ tay thành chuyển động thực tế của xe.

### 4.3.1.5. LED hiển thị trạng thái

Tương tự như mạch phát, mạch thu sử dụng 3 LED để phản hồi trạng thái điều khiển:

LED đỏ (PB12): trạng thái điều khiển theo trục X

LED vàng (PB13): trạng thái theo trục Y

LED xanh (PB14): trạng thái theo trục Z

Các LED này giúp xác nhận tín hiệu đã được nhận và xử lý, đồng thời hỗ trợ kiểm tra hệ thống trong quá trình vận hành và thử nghiệm. Mỗi LED được mắc nối tiếp với điện trở hạn dòng 1KΩ để bảo vệ linh kiện.

### 4.4. Phần mềm hệ thống phát

4.4.1. Driver hoạt động MPU6050.
Driver này là bộ điều khiển để giao tiếp STM32 với cảm biến MPU6050 - một cảm biến 6 trục (3 trục gia tốc + 3 trục con quay hồi chuyển) thông qua giao thức I2C. Nó được thiết kế sử dụng thư viện HAL của ST dành cho vi điều khiển STM32

Driver MPU6050 sẽ lưu trữ dữ liệu thô với kiểu dữ liệu là short được đọc trực tiếp từ các thanh ghi của module MPU6050 và dữ liệu đã xử lý với kiểu dữ liệu là float được tính toán từ dữ liệu thô thông qua công thức chuyển đổi:

// Công thức chuyển đổi gia tốc

acc_x = acc_x_raw / LSB_Sensitivity_ACC;

// Công thức chuyển đổi con quay

gyro_x = gyro_x_raw / LSB_Sensitivity_GYRO;

// Công thức chuyển đổi nhiệt độ

temperature = (temperature_raw / 340.0f) + 36.53f;

Cấu trúc lưu trữ dữ liệu của MPU6050:

typedef struct _MPU6050 {

// ---------- DỮ LIỆU THÔ (RAW DATA) ----------

// Đọc trực tiếp từ cảm biến, chưa qua xử lý

short acc_x_raw; // Giá trị ADC gia tốc trục X (16-bit có dấu)

short acc_y_raw; // Giá trị ADC gia tốc trục Y

short acc_z_raw; // Giá trị ADC gia tốc trục Z

short temperature_raw; // Giá trị ADC nhiệt độ (16-bit có dấu)

short gyro_x_raw; // Giá trị ADC con quay trục X

short gyro_y_raw; // Giá trị ADC con quay trục Y

short gyro_z_raw; // Giá trị ADC con quay trục Z

// ---------- DỮ LIỆU ĐÃ XỬ LÝ ----------

// Đã chuyển đổi sang đơn vị vật lý

float acc_x; | // Gia tốc trục X (đơn vị g, 1g = 9.8m/s²)
float acc_y; | // Gia tốc trục Y
float acc_z; | // Gia tốc trục Z

float temperature; // Nhiệt độ (°C)

float gyro_x; | // Tốc độ góc trục X (°/s)
float gyro_y; | // Tốc độ góc trục Y (°/s)
float gyro_z; | // Tốc độ góc trục Z (°/s)

} Struct_MPU6050;

Hàm khởi tạo MPU6050: void MPU6050_Initialization(void)

Driver MPU6050 bắt đầu với việc khởi tạo kết nối giữa STM32 và module MPU6050 với hàm: void MPU6050_Initialization(void)
Chương trình sẽ kiểm tra kết nối vật lý (WHO_AM_I), chương trình sẽ đọc dữ liệu từ thanh ghi 0x75 và lấy giá trị dữ liệu vừa đọc đó so sánh với giá trị mặc định 0x68 nếu trùng khớp thì hệ thống STM32 và MPU6050 kết nối vật lý thành công, ngược lại nếu so sánh không khớp thì báo lỗi hệ thống STM32 và MPU6050 kết nối vật lý không thành công.

MPU6050_Readbyte(MPU6050_WHO_AM_I, &who_am_i); WHO_AM_I

if (who_am_i == 0x68) {

}

else

{

while (1)

{

HAL_Delay(500);

}

}

Khi hệ thống STM32 và MPU6050 kết nối vật lý thành công thì chương trình sẽ reset cảm biến và thiết lập cài đặt các thông số cơ bản ban đầu như

Cấu hình nguồn clock:

MPU6050_Writebyte(MPU6050_PWR_MGMT_1, 0x01);

HAL_Delay(100);

Cài đặt tần số lấy mẫu:

MPU6050_Writebyte(MPU6050_SMPRT_DIV, 39);

Cấu hình bộ lọc số (DLPF):

MPU6050_Writebyte(MPU6050_CONFIG, 0x00);

Cài đặt thang đo:

MPU6050_Writebyte(MPU6050_GYRO_CONFIG, 0x00 << 3);

MPU6050_Writebyte(MPU6050_ACCEL_CONFIG, 0x00 << 3);

Tính toán độ nhạy LSB:

MPU6050_Get_LSB_Sensitivity(0x00, 0x00);

Cấu hình ngắt (Interrupt):

MPU6050_Writebyte(MPU6050_INT_PIN_CFG, (0x0 << 7) | (0x0 << 5) | (0x1
<< 4));

MPU6050_Writebyte(MPU6050_INT_ENABLE, 0x01);

Hàm | đọc | dữ | liệu | thô: MPU6050_Get6AxisRawData(Struct_MPU6050*
mpu6050_data)
Sau khi driver MPU6050 đã khởi tạo kết nối giữa STM32 và module MPU6050 với hàm void MPU6050_Initialization(void) thì chương trình sẽ bắt đầu thực hiện đọc dữ liệu bắt đầu từ việc đọc dữ liệu thô từ cảm biến với 14byte liên tiếp ( 6 byte gia tốc, 2 byte nhiệt độ và 6 byte gyro).
Chương trình sẽ bắt đầu đọc khối dữ liệu 14 byte dữ liệu thô từ cảm biến MPU6050 bắt đầu từ địa chỉ 0x3B :

uint8_t data_buf[14];

MPU6050_Readbytes(MPU6050_ACCEL_XOUT_H, 14, data_buf);

Chương trình tiếp tục tạo các giá trị đọc cảm biến thô 16 bit từ 14 byte vừa đọc từ cảm biến MPU6050 và lưu vào các giá trị giá trị vào cá cấu trúc lưu trữ dữ liệu của hàm typedef struct _MPU6050 :

mpu6050_data->acc_x_raw = (int16_t)((data_buf[0] << 8) | data_buf[1]);
mpu6050_data->acc_y_raw = (int16_t)((data_buf[2] << 8) | data_buf[3]);
mpu6050_data->acc_z_raw = (int16_t)((data_buf[4] << 8) | data_buf[5]);
mpu6050_data->temperature_raw = (int16_t)((data_buf[6] << 8) | data_buf[7]);
mpu6050_data->gyro_x_raw = (int16_t)((data_buf[8] << 8) | data_buf[9]);
mpu6050_data->gyro_y_raw = (int16_t)((data_buf[10] << 8) | data_buf[11]);

mpu6050_data->gyro_z_raw = (int16_t)((data_buf[12] << 8) | data_buf[13]);

Hàm chuyển đổi dữ liệu: MPU6050_DataConvert(Struct_MPU6050* mpu6050_data)
Sau khi chương trình thực hiện đọc và lưu các giá trị dữ liệu thô từ cảm biến MPU6050 thì chương trình tiếp tục tính toán từ các dữ liệu thô đó sang các đơn vị vật lí với công thức tính toán:

Gia tốc:

mpu6050_data->acc_x = (float)mpu6050_data->acc_x_raw / LSB_Sensitivity_ACC;

mpu6050_data->acc_y = (float)mpu6050_data->acc_y_raw / LSB_Sensitivity_ACC;

mpu6050_data->acc_z = (float)mpu6050_data->acc_z_raw / LSB_Sensitivity_ACC;

Nhiệt độ:

mpu6050_data->temperature = (float)mpu6050_data->temperature_raw / 340.0f + 36.53f;

Gyro:

mpu6050_data->gyro_x = (float)mpu6050_data->gyro_x_raw / LSB_Sensitivity_GYRO;

mpu6050_data->gyro_y = (float)mpu6050_data->gyro_y_raw / LSB_Sensitivity_GYRO;

mpu6050_data->gyro_z | = | (float)mpu6050_data->gyro_z_raw | /
LSB_Sensitivity_GYRO;

Xử lý dữ liệu.
Sau khi đọc và lưu các dữ liệu thô và dữ liệu vật lý sau khi tính toán, chương trình sẽ kiểm tra dữ liệu vừa đọc và lưu vừa thực hiện xong đã sẵn sàn chưa, khi dữ liệu đã sẵn sàng thì chân INT được cài đặt sẽ được kích lên mức high và hàm sẽ trà về là 1, ngược lại nếu dữ liệu chưa sẵn sàng thì chân INT được cài đặt sẽ không được kích lên mức high và hàm sẽ trà về là 0 :

int MPU6050_DataReady(void){

return | HAL_GPIO_ReadPin(MPU6050_INT_PORT, | MPU6050_INT_PIN) | ==
GPIO_PIN_SET;

}

4.4.2. Driver SX1278.
Driver SX1278 cho phép vi điều khiển STM32F103C6T6a giao tiếp và điều khiển module LoRa SX1278. Driver cung cấp cho vi điều khiển STM32 một bộ giao tiếp không dây để thực hiện các tác vụ chính như khởi tạo, cấu hình, gửi và nhận dữ liệu qua sóng LoRa, giúp điều khiển các hệ thống từ xa. Driver SX1278 được phân tách thành lớp logic điều khiển module LoRa SX1278 và lớp trừu tượng phần cứng, giúp tăng tính module hóa và khả năng tái sử dụng.

Lớp trừu tượng phần cứng (Hardware Abstraction Layer) viết tắt là hw là nền tảng cốt lõi của driver. Nó thực hiện tách biệt hoàn toàn phần logic điều khiển module SX1278 với các chi tiết triển khai phần cứng cụ thể trên vi điều khiển STM32. Nó giúp chương trình sạch sẽ và dễ bảo trì ,Nếu muốn chuyển driver này sang một dòng vi điều khiển khác (ví dụ: ESP32, Arduino…), chúng ta chỉ cần viết lại nội dung của lớp này (SX1278_hw.c) để sử dụng các hàm API của nền tảng mới, trong khi toàn bộ lớp logic điều khiển module có thể được giữ nguyên mà không cần chỉnh sửa.

Lớp trừu tượng phần cứng tạo cho chương trình một cấu trúc dữ liệu chứa tất cả thông tin kết nối phần cứng :

typedef struct {

int pin; // Số hiệu chân (ví dụ: GPIO_PIN_5)

void *port; // Cổng GPIO (ví dụ: GPIOA)

} SX1278_hw_dio_t;

typedef struct {

SX1278_hw_dio_t reset; // Chân Reset

SX1278_hw_dio_t dio0; // Chân ngắt DIO0

SX1278_hw_dio_t nss; // Chân Chip Select (SPI NSS)

void *spi; | // Handle SPI (từ HAL)

} SX1278_hw_t;

nss (Network Select Slave): Đây là chân chọn chip. Driver này thực hiện việc điều khiển chân NSS bằng phần mềm. Trước mỗi giao tiếp SPI, driver sẽ kéo chân này xuống mức thấp (LOW) và sau khi kết thúc sẽ kéo lên mức cao (HIGH).
reset: Chân này được kết nối đến chân RESET của module SX1278. Driver sử dụng nó để thực hiện quá trình reset cứng cho module khi cần thiết, để giúp module SX1278 quay về trạng thái mặc định.
dio0: Chân Digital I/O 0 của module SX1278. Đây là chân tín hiệu đầu vào cho vi điều khiển. Nó được module SX1278 sử dụng truyền nhận dữ liệu.
spi: Một con trỏ kiểu void*. Nó sẽ trỏ đến địa chỉ của biến handle SPI do STM32CubeMX tạo ra (ví dụ: &hspi1).
Chương trình khi khởi động sẽ bắt đầu bằng việc khởi tạo phần cứng với hàm __ weak void SX1278_hw_init(SX1278_hw_t *hw), hàm sẽ thiết lập các trạng thái ban đầu đ ặt chân nss ở mức cao để vô hiệu hoá SPI và chân reset ở mức cao để module lora ra02-sx 1278 không bị reset:
__weak void SX1278_hw_init(SX1278_hw_t *hw) {

SX1278_hw_SetNSS(hw, 1); // Tắt chọn chip

HAL_GPIO_WritePin(hw->reset.port, hw->reset.pin, GPIO_PIN_SET); }

Hàm điều khiển GPIO NSS (SX1278_hw_SetNSS) dùng để điều khiển chân nss của module LoRa SX1278 với việc đặt value = 0 chân nss kích mức thấp Lora SX1278 ngừng hoạt động giao tiếp và ngược lại đặt value = 1 chân nss kích mức thấp Lora SX1278 bắt đầu hoạt động giao tiếp:

void SX1278_hw_SetNSS(SX1278_hw_t* hw, int value) {

HAL_GPIO_WritePin(hw->nss.port, hw->nss.pin,

| (value == 1) ? GPIO_PIN_SET : GPIO_PIN_RESET);

}

Hàm điều khiển reset module LoRa SX1278 (SX1278_hw_Reset) dùng để thực hiện việc reset module về thiết lập ban, chương trình đầu bắt đầu thực hiện vời việc ngừng giao tiếp với SPI , kéo chân reset xuống mức thấp (0V), giữ trạng thái reset của module ít nhất 1ms (theo thông số của nhà sản xuất), sau đó kích reset lên mức cao (3.3V) và cuối cùng chương trình chờ 100ms để chờ module LoRa Ra_02 - SX1278 khởi động lại:

void SX1278_hw_Reset(SX1278_hw_t* hw) {

SX1278_hw_SetNSS(hw, 1);

HAL_GPIO_WritePin(hw->reset.port, hw->reset.pin, GPIO_PIN_RESET);

SX1278_hw_DelayMs(1);

HAL_GPIO_WritePin(hw->reset.port, hw->reset.pin, GPIO_PIN_SET);

SX1278_hw_DelayMs(100);

}

Hàm giao tiếp với SPI để gửi dữ liệu (SX1278_hw_SPICommand) dùng để cho module LoRa SX1278 có thể giao tiếp với SPI của vi xử lý STM32 thực hiện vai trò truyền gửi dữ liệu, hàm sẽ thực hiện kéo chân NSS xuống mức thấp (0V), sau đó truyền 1 byte dữ liệu qua chân MOSI và cuối cùng là chờ quá trình hoàn tất:

void SX1278_hw_SPICommand(SX1278_hw_t* hw, uint8_t cmd) {

SX1278_hw_SetNSS(hw, 0);

HAL_SPI_Transmit(hw->spi, &cmd, 1, 1000);

while (HAL_SPI_GetState(hw->spi) != HAL_SPI_STATE_READY);

}

Hàm giao tiếp với SPI để nhận dữ liệu (SX1278_hw_SPIReadByte) dùng để cho module LoRa SX1278 có thể giao tiếp với SPI của vi xử lý STM32 thực hiện vai trò nhận dữ liệu, hàm sẽ thực hiện gửi 1 byte rỗng 0x00 qua MOSI, sau đó gọi hàm HAL_SPI_TransmitReceive để nhận byte dữ liệu từ SX1278 qua MISO cùng lúc:

uint8_t SX1278_hw_SPIReadByte(SX1278_hw_t* hw) {
uint8_t txByte = 0x00;
uint8_t rxByte = 0x00;
HAL_SPI_TransmitReceive(hw->spi, &txByte, &rxByte, 1, 1000);
return rxByte;
}
Hàm đọc trạng thái của chân DIO0 (SX1278_hw_GetDIO0) dùng đề kiểm tra trạng thái của DIO0 nếu như chân này đang trong quá trình đọc hoặc nhận dữ liệu thì chân này sẽ ở mức cao và ngược lại nếu chân này không hoạ động thì chân này sẽ ở mức thấp: __weak int SX1278_hw_GetDIO0(SX1278_hw_t *hw) {

return (HAL_GPIO_ReadPin(hw->dio0.port, hw->dio0.pin) == GPIO_PIN_SET);

}

Sơ đồ khối hoạt động của chương trình của lớp trừu tượng phần cứng:

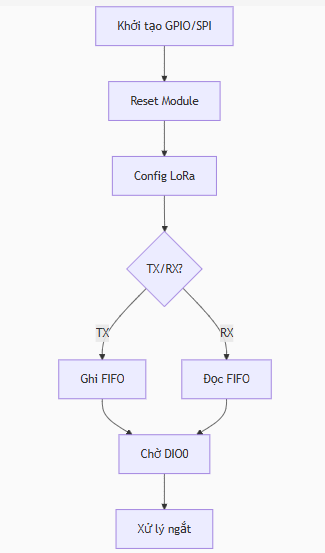
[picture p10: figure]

Hinh 4.3: lưu đồ thuật toán

Lớp logic điều khiển module LoRa SX1278
Lớp điều khiển LoRa (SX1278) là lớp quản lý giao tiếp giữa vi xử lý STM32 với module LoRa SX1278 thông qua lớp phần cứng, cung cấp các chức năng:

Cấu hình thông số hoạt động của LoRa (tần số, công suất, SF, BW, CR).
Truyền và nhận dữ liệu không dây thông qua giao thức LoRa.
Quản lý trạng thái hoạt động module LoRa (Sleep/Standby/TX/RX).
Ở lớp điều khiển LoRa (SX1278) này có cấu trúc dữ liệu như sau:

typedef struct {

SX1278_hw_t *hw;

uint64_t frequency;

uint8_t power;

uint8_t LoRa_SF;

uint8_t LoRa_BW;

uint8_t LoRa_CR;

uint8_t LoRa_CRC_sum;

uint8_t packetLength;

SX1278_Status_t status;

uint8_t rxBuffer[SX1278_MAX_PACKET];

uint8_t readBytes;

} SX1278_t;

Hàm sử dụng con trỏ đến phần cứng *hw để giao tiếp với SPI và thiết lập điều khiển các chân NSS,RESET,DIO0. Hàm còn thực hiện công việc cài đặt các giá trị thông số hoạt động của LoRa như sau:

frequency | 862–1020 MHz (tùy khu vực) | Tần số hoạt động, ví dụ 868000000 cho 868MHz
power | 0 (20dBm) – 3 (11dBm) | Công suất phát, sử dụng mảng SX1278_Power[] để chuyển đổi
LoRa_SF | 6–12 | Spreading Factor (độ rộng symbol), ảnh hưởng đến tốc độ và độ nhạy
LoRa_BW | 0 (7.8kHz) – 9 (500kHz) | Băng thông, sử dụng mảng SX1278_LoRaBandwidth[]
LoRa_CR | 0 (4/5) – 3 (4/8) | Tỉ lệ mã hóa, ảnh hưởng đến khả năng chống nhiễu
LoRa_CRC_sum | 0 (Enable) hoặc 1 (Disable) | Kiểm tra CRC để phát hiện lỗi

Bảng 4.2. thông số lora

Quản lý trạng thái hoạt động của LoRa: typedef enum _SX1278_STATUS {

SLEEP,

STANDBY,

TX,

RX

} SX1278_Status_t;

và cuối cùng là thực hiện việc quản lý dữ liệu truyền nhận:

uint8_t rxBuffer[SX1278_MAX_PACKET];

uint8_t readBytes;

Các hàm trong chương trình để hoạt động quá trình truyền nhận dữ liệu bằng module LoRa:

Hàm Khởi Tạo Module (SX1278_init) dùng để thiết lập các tham số hoạt động của module LoRa ( tần số, công suất, SF, BW, CR, CRC), khởi tạo phần cứng (SPI , GPIO) và cuối cùng là cấu hình các thanh ghi của module LoRa thông qua hàm SX1278_config:

void SX1278_init(SX1278_t *module, uint64_t frequency, uint8_t power,

uint8_t LoRa_SF, uint8_t LoRa_BW, uint8_t LoRa_CR,

uint8_t LoRa_CRC_sum, uint8_t packetLength) {

module->frequency = frequency;

module->power = power;

module->LoRa_SF = LoRa_SF;

module->LoRa_BW = LoRa_BW;

module->LoRa_CR = LoRa_CR;

module->LoRa_CRC_sum = LoRa_CRC_sum;

module->packetLength = packetLength;

SX1278_hw_init(module->hw);

SX1278_config(module);

}

Hàm cấu hình LoRa (SX1278_config) chương trình thực hiện chuyển chế động module sang sleep, sau đó chuyển sang chế độ LoRa và thiết lập tần số thông qua tính toán các giá trị thanh ghi từ tần số mong muốn , thiết lập công suất dùng bảng SX1278_Power[] để chọn mức phù hợp, thiết lập cấu hình Implicit Header mode và cuối cùng chuyển sang chế độ Standby:

void SX1278_config(SX1278_t *module) {

SX1278_sleep(module); // Chuyển về chế độ Sleep

SX1278_entryLoRa(module); // Chuyển sang chế độ LoRa

uint64_t freq_reg = ((uint64_t)module->frequency << 19) / 32000000;

uint8_t freq_buf[3] = {

(uint8_t)(freq_reg >> 16),

(uint8_t)(freq_reg >> 8),

(uint8_t)freq_reg

};

SX1278278_SPIWrite(module, LR_RegLna, 0x23); // LNA gain

if (module->LoRa_SF == 6) {

SX1278_SPIWrite(module, LR_RegModemConfig1, 0x72);

}

else {

SX1278_SPIWrite(module, LR_RegModemConfig1, 0x74);

}

SX1278_standby(module); // Chuyển sang Standby

}

Hàm Truyền Dữ Liệu (SX1278_transmit) dùng để thực hiện quá trình truyền dữ liệu không dây thông qua module LoRa, chương trình sẽ cấu hình cho LoRa ở chế độ TX và thiết lập FIFO, sau đó thực hiện ghi dữ liệu cần truyền vào FIFo và bắt đầu truyền và cuối cùng là chờ ngắt timeout:

int SX1278_transmit(SX1278_t *module, uint8_t *txBuf, uint8_t length, uint32_t timeout) {

if (SX1278_LoRaEntryTx(module, length, timeout)) {

return SX1278_LoRaTxPacket(module, txBuf, length, timeout);

}

return 0;

}

Hàm Nhận Dữ Liệu (SX1278_receive) dùng để thực hiện quá trình nhận dữ liệu không dây thông qua module LoRa, chương trình sẽ cấu hình cho LoRa ở chế độ nhận RX và và bật ngắt RX Done, sau đó kiểm tra DIO0 và đọc dữ liệu từ FIFO, và dữ liệu đó sẽ được lưu vao rxBuffer với độ dài là readBytes:

int SX1278_receive(SX1278_t *module, uint8_t length, uint32_t timeout) {

return SX1278_LoRaEntryRx(module, length, timeout);

}

uint8_t SX1278_available(SX1278_t *module) {

return SX1278_LoRaRxPacket(module);

}

Sơ đồ khối hoạt động của chương trình của lớp logic điều khiển module LoRa SX1278 :

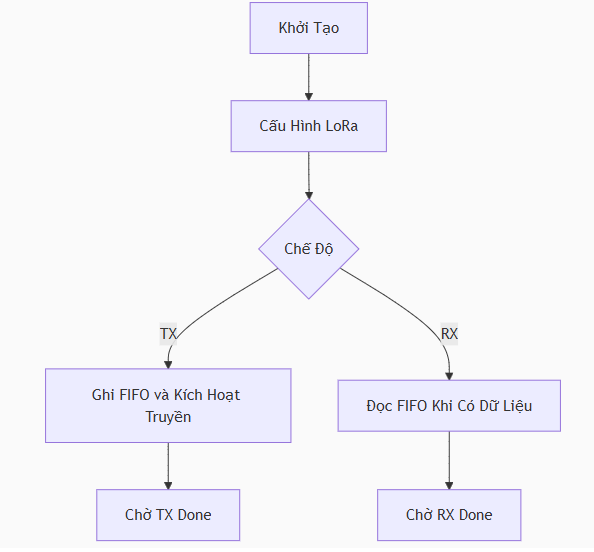
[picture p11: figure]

Hinh 4.4: lưu đồ thuật toán

4.4.3. Chương trình hệ thống đọc dữ liệu MPU6050 và truyền dữ liệu.

Chương trình được xử lý bởi vi xử lý STM32F103C6T6a với các chân GPIO kết nối với module MPU6050 thông qua I2C và kết nối với module LoRa RA02-SX1278 được

cấu hình như sau:

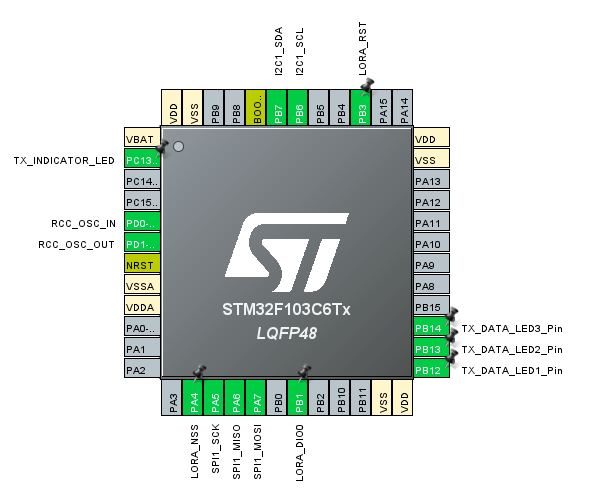
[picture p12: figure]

Hinh 4.5: thiết lập cấu hình

Với cấu hình Clock Configuration với High Speed Clock (HSE) được cấu hình là Crytal/ceramic và thông số HCLK là 72MHz

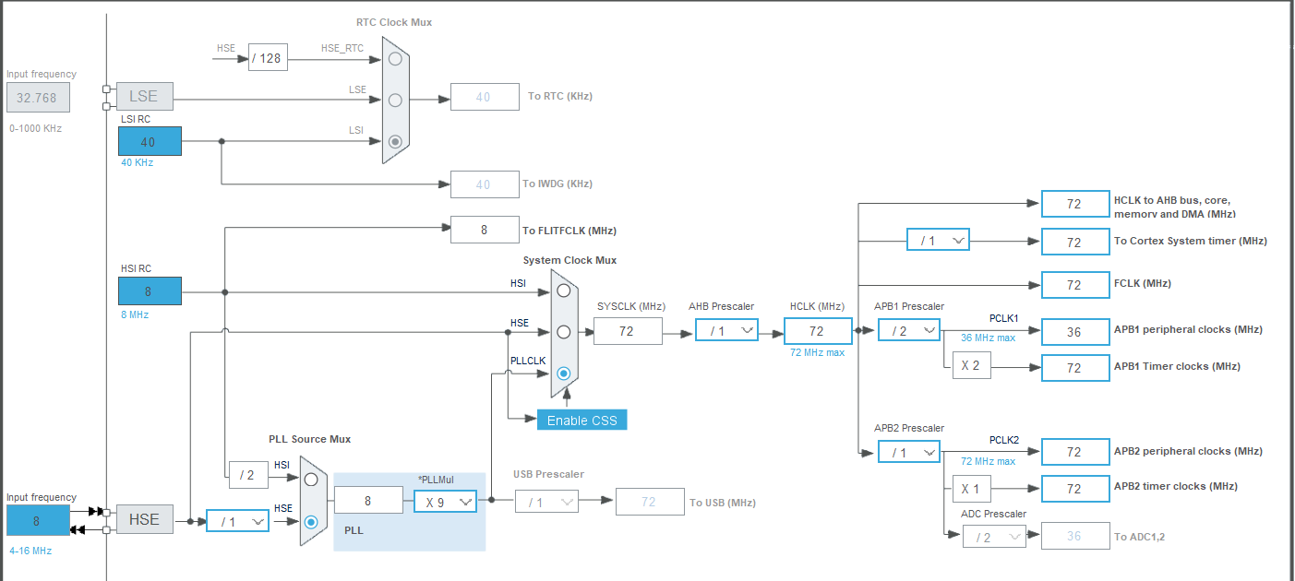
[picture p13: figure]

Hinh 4.6: thiết lập cấu hình

Vi xử lý STM32 sử dụng giao thức I2C1 để kết nối với MPU 6050 với chân PB7-I2C_SDA và chân PB8-I2C_SCL với thông số cài đặt

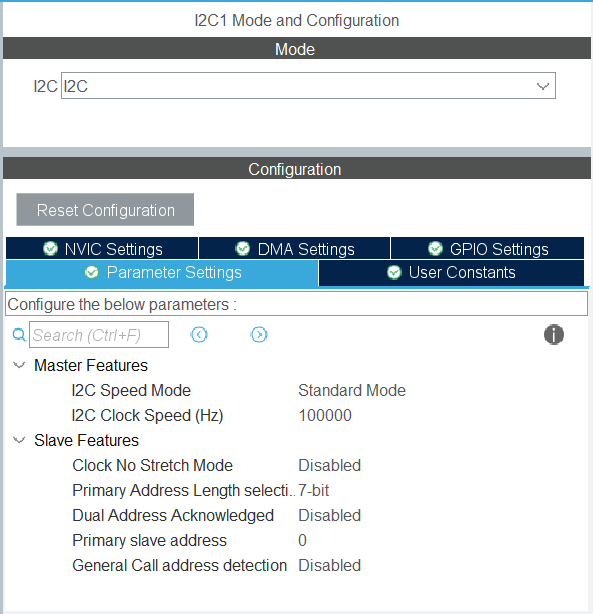
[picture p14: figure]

Hinh 4.7: thiết lập cấu hình

Vi xử lý STM32 sử dụng giao thức SPI1 để kết nối với LoRa SX1278 với chân PA5-SCK , chân PA6-MISO, CHÂN PA7-MOSI và các chân thiết lập GPIO OUTPUT như chân PB1-DIO0, chân PB3-RESET, chân PA4-NSS. Được cài đặt thông số SPI1:

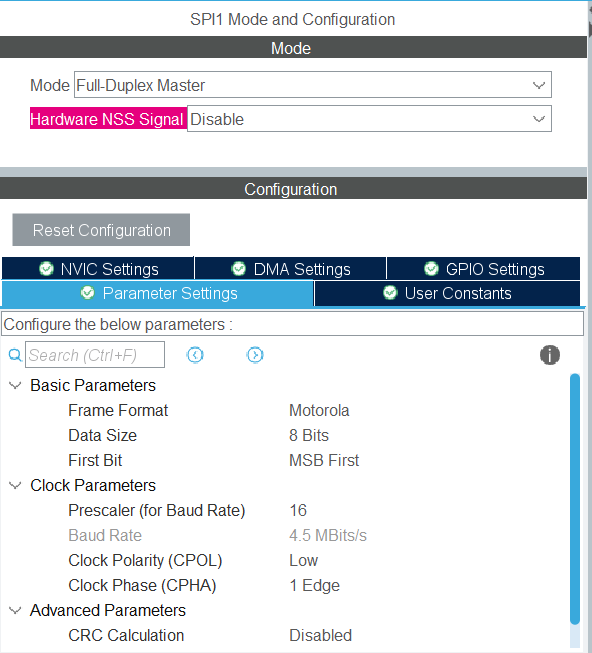
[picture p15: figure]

Hinh 4.8: thiết lập cấu hình

Chương trình sử dụng vi xử lý đọc cảm biến góc nghiên MPU6050 và gửi dữ liệu bằng LoRa. Chương trình bắt đầu bằng việc khởi tạo các thư viện

int main(void) {

HAL_Init();

SystemClock_Config();

MX_GPIO_Init();

MX_SPI1_Init();

MX_I2C1_Init();

// ...

}

Sau khi khởi tạo các thư viện, chương trình bắt đầu khởi tạo MPU 6050 và thiết lập các thông số cho MPU hoạt động:

if (HAL_I2C_IsDeviceReady(&hi2c1, MPU6050_I2C_ADDR, 3, 100) != HAL_OK) {

system_status_flag = 1;

Indicate_Overall_Status(0);

}

while (MPU6050_Init_Device() != HAL_OK && system_status_flag == 0) {

system_status_flag = 2;

Indicate_Overall_Status(4);

HAL_Delay(2000);

}

if (system_status_flag == 0) {

system_status_flag = 0;

Indicate_Overall_Status(1);

}

Sơ đồ khối khởi tạo giữa STM32 và MPU6050 thông qua giao thức I2C:

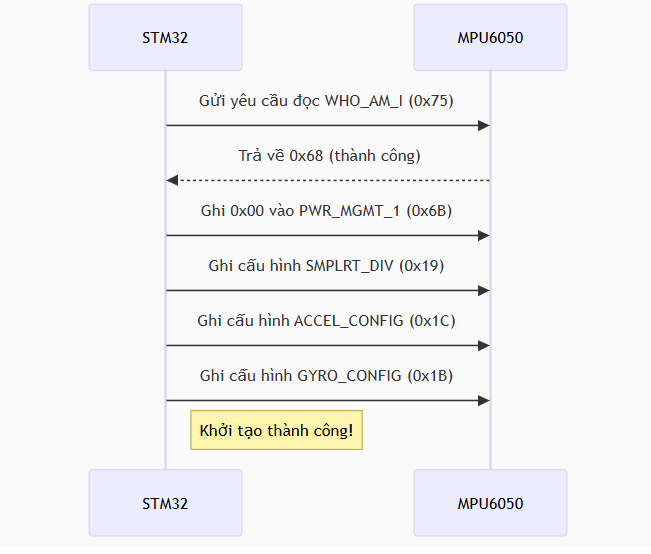
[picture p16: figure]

Hinh 4.9: thiết lập cấu hình

Tiếp tục chương trình sẽ khởi tạo LoRa thiết lập các thông số cho LoRa hoạt động:

if (system_status_flag == 0) {

LoRa_HW_TX.spi = &hspi1;

LoRa_HW_TX.nss.port = LORA_NSS_GPIO_Port; LoRa_HW_TX.nss.pin = LORA_NSS_Pin;

LoRa_HW_TX.reset.port = LORA_RST_GPIO_Port; LoRa_HW_TX.reset.pin = LORA_RST_Pin;

LoRaModule_TX.hw = &LoRa_HW_TX;

SX1278_hw_Reset(&LoRa_HW_TX);

SX1278_init(&LoRaModule_TX,

LORA_FREQUENCY_HZ, LORA_TX_POWER, LORA_SF,

LORA_BANDWIDTH, LORA_CODING_RATE, LORA_CRC_ENABLE,

LORA_PACKET_MAX_LEN);

uint8_t version = SX1278_SPIRead(&LoRaModule_TX, REG_LR_VERSION);

if (version == 0x12) {

Indicate_Overall_Status(1);

} else {

system_status_flag = 3; // LoRa init failed

Indicate_Overall_Status(0); // Dừng với lỗi nghiêm trọng } }

Các thông số được cài đặt để LoRa hoạt động:

SF (Spreading Factor) | 7 | Tốc độ cao, khoảng cách ngắn
BW (Bandwidth) | 125kHz | Độ rộng kênh cân bằng
CR (Coding Rate) | 4/5 | Hiệu suất truyền cao
Tần số | 433MHz | Phổ ISM, khoảng cách tốt
Công suất | 17dBm | Cân bằng giữa phạm vi và tiêu thụ năng

lượng
Bảng 4.3 thông số lora

Sơ đồ khối quá trình khởi tạo giữa STM32 và LoRa SX1278 thông qua giao thức SPI:

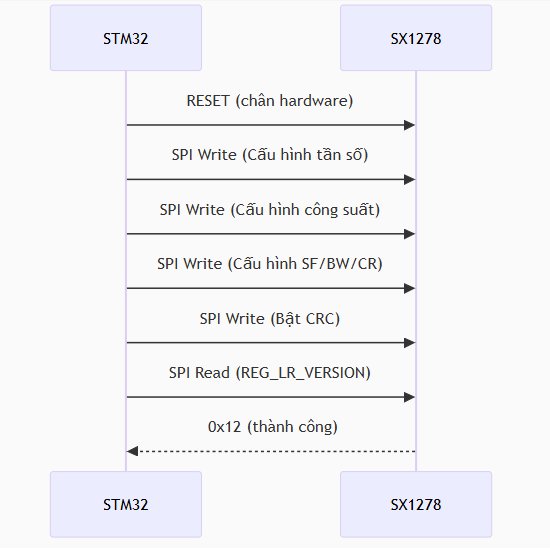
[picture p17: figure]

Hinh 4.10: thiết lập cấu hình

Sau khi chương trình khởi động các thư viện cần thiêt scho hệ thống, chương trình sẽ bắt đầu chạy vào vòng lặp while

Ở trong vòng lặp này chương trình sẽ thực hiện đọc 6 byte liên tiếp từ thanh ghi ACCEL_XOUT_H của MPU6050 và sau đó tính toán chuyển sang giá trị vật lí và lưu trữ với công thức

mpu_data.Ax = raw_value / 16384.0f;

Từ giá trị vật lý vừa được lưu trữ chương trình sẽ tiếp tục so sánh các giá trị đó để biết được MPU6050 đang ở trạng thái góc nghiêng nào.

Từ góc nghiên đó vi xử lý STM32 sẽ thực hiện điều khiển Led tương ứng và lưu bằng 1 giá trị có kích thước 1 byte để truyền dữ liệu bằng LoRa với bảng giá trị

0 | Phẳng | Tất cả tắt
1 | Nghiêng phải | PB12 sáng
2 | Nghiêng trái | PB12 sáng

3 | Ngửa lên | PB14 sáng
4 | Cúi xuống | PB13 sáng
Bảng 4.4. thiết lập mpu6050

Cuối cùng hệ thống sẽ truyền dữ liệu vừa được lưu trữ thông qua LoRa đã cài đặt và hệ thống sẽ delay 200 ms để hệ thống chạy ổng định hơn

Sơ đồ khối hoạt động của hệ thống phát dữ liệu:

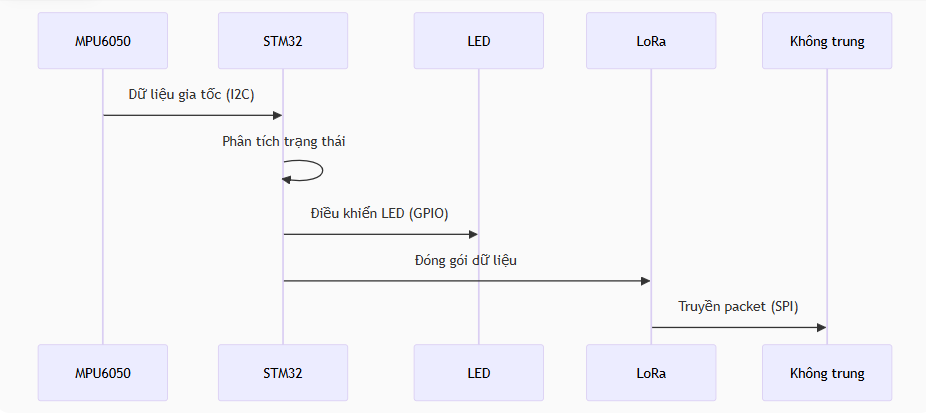
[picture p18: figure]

Hinh 4.11: thiết lập cấu hình

### 4.5. Phần mềm hệ thống thu

Chương trình được xử lý bởi vi xử lý STM32F103C6T6a với các chân GPIO kết nối với module LoRa RA02-SX1278 và bộ điều khiển đông cơ L298 được kết nối như sau:

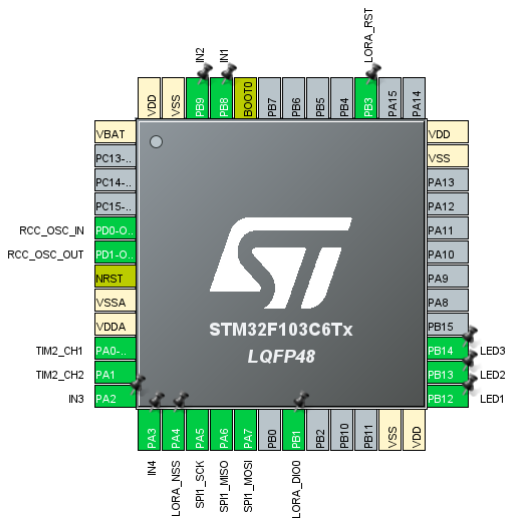
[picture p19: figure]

Hinh 4.12: thiết lập cấu hình

Với cấu hình Clock Configuration với High Speed Clock (HSE) được cấu hình là Crytal/ceramic và thông số HCLK là 72MHz

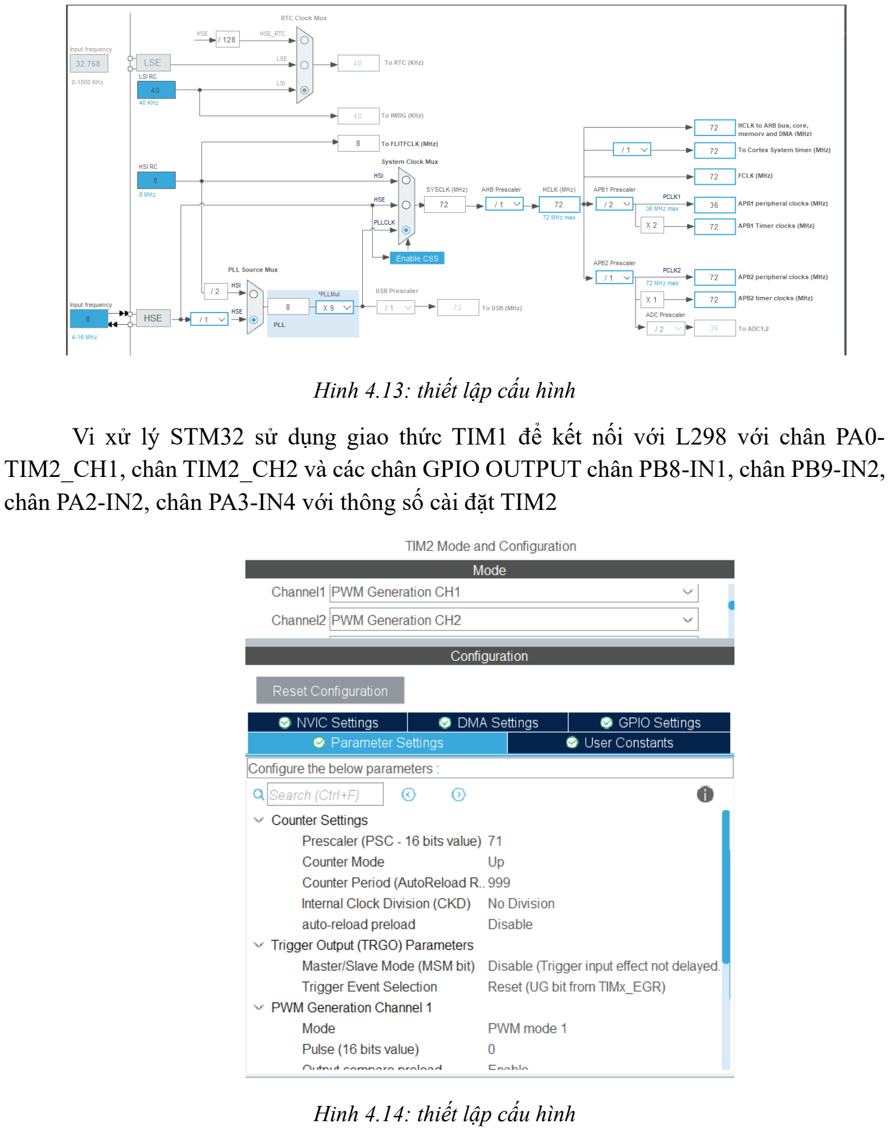
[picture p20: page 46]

Hinh 4.13: thiết lập cấu hình

Vi xử lý STM32 sử dụng giao thức TIM1 để kết nối với L298 với chân PA0-TIM2_CH1, chân TIM2_CH2 và các chân GPIO OUTPUT chân PB8-IN1, chân PB9-IN2, chân PA2-IN2, chân PA3-IN4 với thông số cài đặt TIM2

Hinh 4.14: thiết lập cấu hình

Vi xử lý STM32 sử dụng giao thức SPI1 để kết nối với LoRa SX1278 với chân PA5-SPI_SCK , chân PA6-SPI_MISO, CHÂN PA7-SPI_MOSI và các chân thiết lập GPIO OUTPUT như chân PB3-RESET, chân PA4-NSS và cuối cùng chân PB1-DIO0 được cài đặt cấu hình là EXTI. Được cài đặt thông số SPI1:

Hinh 4.15: thiết lập cấu hình

Chương trình sử dụng vi xử lý STM32 nhận dữ liệu được gửi bằng LoRa và từ dữ liệu đó STM32 điều khiển động cơ DC thông qua bộ điều khiển động cơ L298. Chương trình bắt đầu bằng việc khởi tạo các thư viện

int main(void) {

HAL_Init();

SystemClock_Config();

MX_GPIO_Init();

MX_SPI1_Init();

MX_TIM2_Init();

// ...

}

Sau khi khởi tạo các thư viện, chương trình bắt đầu khởi tạo LoRa SX1278 và thiết lập các thông số cho LoRa SX1278 hoạt động, các thông số LoRa nhận dữ liệu này phải trùng khớp với LoRa ở đầu phát thì hệ thống mới truyền nhận dữ liệu thành công và đặt cho module LoRa ở chế độ nhận dữ liệu liên tục không ngừng nghỉ:

SX1278_hw_t LoRa_HW_RX = {

.spi = &hspi1, | // SPI1

.nss.port = LORA_NSS_GPIO_Port, .nss.pin = LORA_NSS_Pin,

.reset.port = LORA_RST_GPIO_Port, .reset.pin = LORA_RST_Pin,

.dio0.port = LORA_DIO0_GPIO_Port, .dio0.pin = LORA_DIO0_Pin

};

SX1278_hw_Reset(&LoRa_HW_RX);

SX1278_init(&LoRaModule_RX,

LORA_FREQUENCY_HZ,

LORA_POWER,

LORA_SF,

LORA_BANDWIDTH,

LORA_CODING_RATE,

LORA_CRC_ENABLE,

LORA_PACKET_LEN_CONFIG

);

uint8_t version = SX1278_SPIRead(&LoRaModule_RX, REG_LR_VERSION);

if(version == 0x12) { /* SX1278 hợp lệ */ }

SX1278_receive(&LoRaModule_RX,LORA_PACKET_LEN_CONFIG,SX1278_DEFAUL T_TIMEOUT);

Sau khi khởi động LoRa thành công hệ thống bắt đầu tiếp tục khởi tạo 2 kênh PWM bằng TIM2 đã cài đặt bằng STM32CubeIDE, hệ thống sử dụng HAL để khởi tạo 2 kênh PWM và cài đặt thống số tốc độ:

HAL_TIM_PWM_Start(&htim2, TIM_CHANNEL_1);

HAL_TIM_PWM_Start(&htim2, TIM_CHANNEL_2);

#define SPEED_FULL 999

#define SPEED_RUN 200

#define SPEED_TURN 150

Vì chân DIO0 của LoRa được cấu hình là ngắt nên khi nhận tín hiệu thì chân DIO0 sẽ được kích lên mức cao để báo hiệu có dữ liệu mới:

void HAL_GPIO_EXTI_Callback(uint16_t GPIO_Pin) {

if (GPIO_Pin == LORA_DIO0_Pin) {

loraPacketReadyFlag_RX = 1;

}

}

Để hệ thống không bị bỏ xót dữ liệu mới trong vong lặp while của chương trình có lệnh xoá bỏ cờ ngắt khi chân DIO0 ở mức cao thì ngay tập tức sẽ bị kéo xuống mức thấp để không bỏ xót dữ liệu nào
Tiếp theo chương trình sẽ kiểm tra dữ liệu vừa nhận được có độ dài bao nhiêu, bao nhiêu byte và so sánh nên số byte lớn hơn 0 thì chương trình bắt đầu đọc dữ liệu các byte từ bộ đệm của LoRa.

Từ dữ liệu vừa nhận được vi xử lý STM32 điều khiển động cơ thông qua TIM2 và đồng thời sáng đèn LED tương ứng với bảng dữ liệu sau

0 | Đứng yên | Tất cả tắt
1 | Xoay sang phải | PB12 sáng
2 | Xoay sang trái | PB12 sáng
3 | Lui về | PB14 sáng
4 | Tiến tới | PB13 sáng

Bảng 4.5. thiết lập Led

Cơ chế điều khiển PWM (Pulse Width Modulation) là kỹ thuật điều chỉnh điện áp hiệu dụng bằng cách thay đổi độ rộng xung, độ rộng sung càng nhỏ thì động cơ càng mạnh mạnh nhất là 999 ở SPEED_FULL và đứng yên ở SPEED-STOP

void motor1_set_speed(uint16_t speed_pulse) {

// Giới hạn giá trị PWM trong phạm vi cho phép

if (speed_pulse > SPEED_FULL) speed_pulse = SPEED_FULL;

// Cập nhật giá trị PWM cho kênh TIM2 CH1

__HAL_TIM_SET_COMPARE(&htim2, MOTOR1_PWM_CHANNEL, speed_pulse);

}

Bảng dữ liệu

Giá trị PWM | Tốc độ | Ví dụ
0 | Dừng | Xe đứng yên
150 | Chậm | Xe chạy chậm
200 | Vừa | Tốc độ bình thường
999 | Nhanh | Tốc độ nhanh
Bảng 4.6. thiết lập tốc độ L298

Cơ chế điều khiển động cơ: việc điều khiển động cơ hoạt động với tiến bằng cách kích chân IN1 và lùi bằng cách kích chân IN2, còn PWN như bộ điều khiển tốc độ quyết định động cơ đó chạy với tốc độ bao nhiêu:

IN1 | IN2 | Hướng chạy | Ví dụ
1 | 0 | Tiến | Xe chạy thẳng
0 | 1 | Lùi | Xe chạy lùi
0 | 0 | Tự do | Xe dừng từ từ
1 | 1 | Phanh đứng yên | Xe đứng yên
Bảng 4.7. thiết lập động cơ L298

Vòng lặp While thực hiện liên tục không delay để cho việc nhận dữ liệu hiệu quả không bị bỏ xót dữ liệu nào từ LoRa

CHƯƠNG 5: KẾT QUẢ THỰC NGHIỆM

5.1: Mô hình phần cứng và thực tế

5.1.1: Phần cứng hệ thống phát

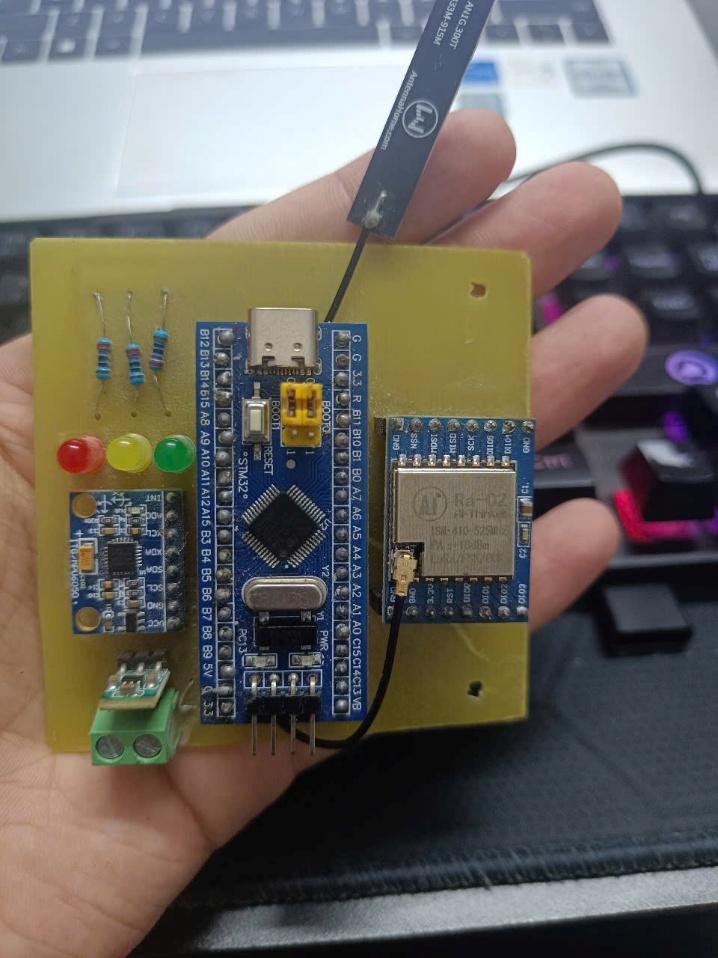
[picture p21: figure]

Hinh 5.1: phần cứng phát

Bo mạch được thiết kế nhỏ gọn và bố trí hợp lý trên một bảng mạch in (PCB), giúp dễ dàng tích hợp vào các thiết bị di động hoặc hệ thống xe điều khiển từ xa. Các linh kiện chính được hàn cố định chắc chắn trên PCB, đảm bảo kết nối ổn định và an toàn trong quá trình sử dụng.

Vi điều khiển STM32F103C8T6 (blue pill) được gắn ở trung tâm bo mạch, đóng vai trò xử lý chính. Cạnh bên phải là module truyền thông LoRa Ra-02 được gắn trên module chuyển mức logic, kết nối với STM32 qua giao tiếp SPI. Ăng-ten LoRa được kéo ra ngoài, giúp tăng cường khả năng thu phát tín hiệu trong môi trường rộng.

Ba đèn LED báo trạng thái (đỏ, vàng, xanh) được bố trí thẳng hàng phía trên bên trái của bo mạch, đi kèm với các điện trở hạn dòng 1KΩ, giúp hiển thị trạng thái tín hiệu hoặc quá trình xử lý từ MPU6050 một cách trực quan.

Phía dưới cùng bên trái là cảm biến MPU6050, được cố định trực tiếp trên PCB bằng chân header để thuận tiện trong quá trình tháo lắp, thử nghiệm. Cảm biến này sẽ ghi nhận chuyển động của tay người điều khiển và gửi dữ liệu về STM32.

Đầu cấp nguồn được đưa ra phía dưới của bo mạch, sử dụng terminal 2 chân chắc chắn để kết nối với pin hoặc adapter. Việc đi dây ngắn gọn, cố định giúp hạn chế đứt, lỏng dây trong điều kiện di chuyển hoặc rung lắc.

5.1.1: Phần cứng hệ thống thu

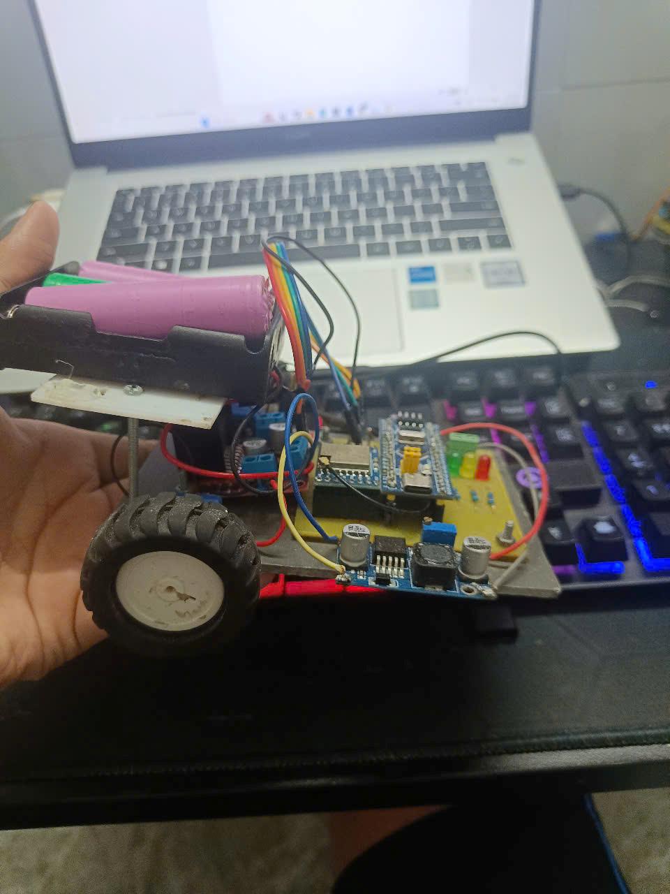
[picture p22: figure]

Hinh 5.2: phần cứng thu

Bo mạch thu được lắp đặt trực tiếp lên khung xe điều khiển hai bánh, kết nối với hệ thống động cơ thông qua mạch điều khiển cầu H L298. Mô hình xe sử dụng khung nhựa nhẹ, dễ gia công, giúp giảm trọng lượng và tối ưu hiệu suất hoạt động.

Trên xe, bo mạch thu gồm các thành phần chính:

Vi điều khiển STM32F103C8T6 nằm ở trung tâm mạch, xử lý tín hiệu từ LoRa và điều khiển động cơ theo lệnh nhận được.

Module LoRa gắn bên cạnh vi điều khiển để nhận tín hiệu điều khiển từ xa thông qua sóng RF.

Bộ điều khiển động cơ L298 được kết nối với 2 động cơ DC của xe, điều khiển hướng quay và tốc độ của động cơ trái/phải.

Ba đèn LED báo trạng thái hỗ trợ hiển thị dữ liệu hoặc tín hiệu điều khiển đã nhận được.

Module nguồn hạ áp được sử dụng để chuyển đổi điện áp từ pin Li-ion (7.4V) xuống mức 5V hoặc 3.3V phù hợp cho các linh kiện nhạy dòng như STM32 và LoRa.

Nguồn cấp chính cho toàn hệ thống là hai viên pin Li-ion 18650 được đặt trong giá đỡ phía sau xe. Pin được hàn dây chắc chắn và cố định bằng khung nhôm để đảm bảo ổn định trong quá trình di chuyển.

Toàn bộ hệ thống dây tín hiệu và dây nguồn được đi gọn gàng bằng dây jump hoặc dây dupont nhiều màu, giúp dễ quan sát và khắc phục sự cố. Bánh xe được kết nối trực tiếp với trục động cơ, đảm bảo xe có thể di chuyển linh hoạt theo các lệnh điều khiển như tiến, lùi, rẽ trái, rẽ phải.

Việc tích hợp mạch thu vào mô hình xe hoàn chỉnh đã tạo nên một hệ thống điều khiển từ xa hoàn chỉnh, có khả năng phản hồi nhanh và hoạt động ổn định trong môi trường thực tế

CHƯƠNG 6: KẾT LUẬN VÀ BÀI HỌC

### 6.1. kết luận

Đề tài "Điều khiển xe bằng MPU6050 thông qua LoRa" đã được nghiên cứu, thiết kế và triển khai hoàn chỉnh, đạt được các mục tiêu đặt ra ban đầu. Hệ thống cho phép người dùng điều khiển xe từ xa thông qua cử chỉ tay, sử dụng cảm biến chuyển động MPU6050 để thu thập dữ liệu, xử lý bằng vi điều khiển STM32F103C8 và truyền không dây qua module LoRa.

Thông qua quá trình thực nghiệm, hệ thống hoạt động ổn định ở khoảng cách truyền vài trăm mét trong điều kiện không vật cản. Xe phản hồi nhanh với các chuyển động tay cơ bản như tiến, lùi, rẽ trái, rẽ phải. Việc sử dụng LoRa giúp hệ thống tiết kiệm năng lượng, không phụ thuộc vào hạ tầng mạng WiFi hay Bluetooth, phù hợp với các ứng dụng ngoài trời hoặc trong môi trường không có kết nối internet.

### 6.2. Bài học

Thông qua quá trình nghiên cứu và triển khai đề tài “Điều khiển xe bằng MPU6050 thông qua LoRa”, nhóm đã tích lũy được nhiều bài học chuyên sâu trong quá trình làm việc thực tế với hệ thống nhúng, cảm biến và truyền thông không dây. Cụ thể như sau:

Hiểu sâu về cấu trúc và cơ chế hoạt động của MPU6050:

Nhóm không chỉ dừng lại ở việc đọc giá trị cơ bản từ cảm biến, mà đã tìm hiểu chi tiết các thanh ghi cấu hình bên trong MPU6050. Việc lựa chọn dải đo, cấu hình tốc độ lấy mẫu và hiểu rõ nguyên lý hoạt động của DMP (Digital Motion Processor) giúp nhóm xử lý tín hiệu ổn định hơn. Nhóm cũng rút ra được kinh nghiệm trong việc chuyển đổi dữ liệu thô sang góc nghiêng thực tế và áp dụng thuật toán lọc để giảm sai số.

Làm chủ cấu hình truyền thông LoRa và tối ưu hóa thông số:

Nhóm đã nghiên cứu và thử nghiệm các thông số quan trọng của LoRa như: Spreading Factor (SF), Bandwidth (BW) và Coding Rate (CR), từ đó cân bằng giữa tốc độ truyền và khoảng cách truyền phù hợp với môi trường sử dụng. Ngoài ra, việc lựa chọn chế độ phát công suất và cấu hình SPI cũng được thực hiện một cách chủ động thay vì phụ thuộc hoàn toàn vào thư viện.

Ứng dụng thành thạo STM32 cả ở mức HAL và thanh ghi:

Bên cạnh việc sử dụng thư viện HAL để lập trình nhanh, nhóm cũng đã tìm hiểu và thao tác ở mức thanh ghi trong một số khối ngoại vi như SPI, GPIO và Timer để nâng cao hiệu suất và độ kiểm soát của chương trình. Qua đó, nhóm hiểu rõ hơn về cấu trúc bộ nhớ, hệ thống clock và ngắt (interrupt) của STM32.

TÀI LIỆU THAM KHẢO

[1] TapIT. (2023). Hướng dẫn sử dụng STM32CubeMX và Keil C lập trình STM32. Truy cập từ:
https://www.tapit.vn/huong-dan-su-dung-stm32cubemx-va-keil-c-lap-trinh-stm32/
[2] DocHelp.net. (2022). Tổng quan vi điều khiển STM32F103C8T6 và cách sử dụng Keil. Truy cập từ:
https://pdfcoffee.com/dochelpnet-tong-quan-stm32f103c8t6-va-cach-su-dung-keilpdf-pdf-free.html (https://pdfcoffee.com/dochelpnet-tong-quan-stm32f103c8t6-va-cach-su-dung-keilpdf-pdf-free.html)
[3] Scribd. (2023). Lập trình vi xử lý bằng chip STM32F103C8T6 theo yêu cầu. Truy cập từ:
https://www.scribd.com/document/669670633/L%E1%BA%ADp-Tr%C3%ACnh-Vi-X%E1%BB%AD-L%C3%BD-b%E1%BA%B1ng-Chip-STM32F103C8T6-Theo-Y%C3%AAu-C%E1%BA%A7u (https://www.scribd.com/document/669670633/L%E1%BA%ADp-Tr%C3%ACnh-Vi-X%E1%BB%AD-L%C3%BD-b%E1%BA%B1ng-Chip-STM32F103C8T6-Theo-Y%C3%AAu-C%E1%BA%A7u)
[4] Laptrinhdientu.com. (2022). Giới thiệu cảm biến chuyển động MPU6050 và hướng dẫn sử dụng. Truy cập từ:
https://www.laptrinhdientu.com/2022/08/MPU6050.html
[5] Studocu.vn. (2022). Cảm biến gia tốc MPU6050 – phân tích và xử lý tín hiệu. https://www.studocu.vn/vn/document/truong-dai-hoc-bach-khoa-ha-noi/cam-bien-gia-toc-mpu6050/114841568 (https://www.studocu.vn/vn/document/truong-dai-hoc-bach-khoa-ha-noi/cam-bien-gia-toc-mpu6050/114841568)
[6] 4Evn.com. (2021). Cách sử dụng module LoRa SX1278 433MHz. https://www.4evn.com/2021/01/cach-su-dung-module-lora-sx1278-433mhz.html
[7] OhStem Education. (2023). Module LoRa E32 – tài liệu kỹ thuật và cấu hình truyền không dây
https://docs.ohstem.vn/en/latest/module/cam-bien/lora.html
[8] Dientu360.com. (2022). Module thu–phát RF LoRa SX1278 UART 3km (AS62-T20) https://dientu360.com/module-thu-phat-rf-lora-sx1278-433mhz-uart-3km-as62-t20

PHỤ LỤC

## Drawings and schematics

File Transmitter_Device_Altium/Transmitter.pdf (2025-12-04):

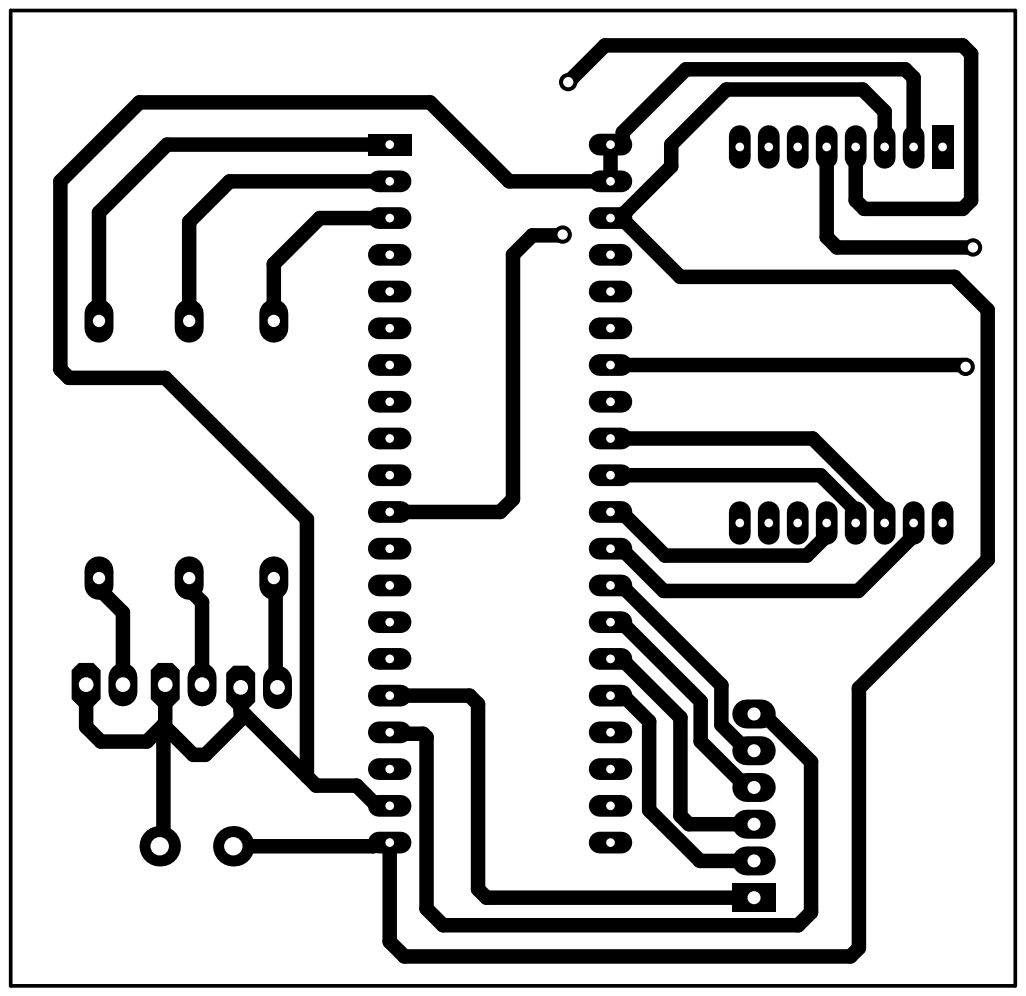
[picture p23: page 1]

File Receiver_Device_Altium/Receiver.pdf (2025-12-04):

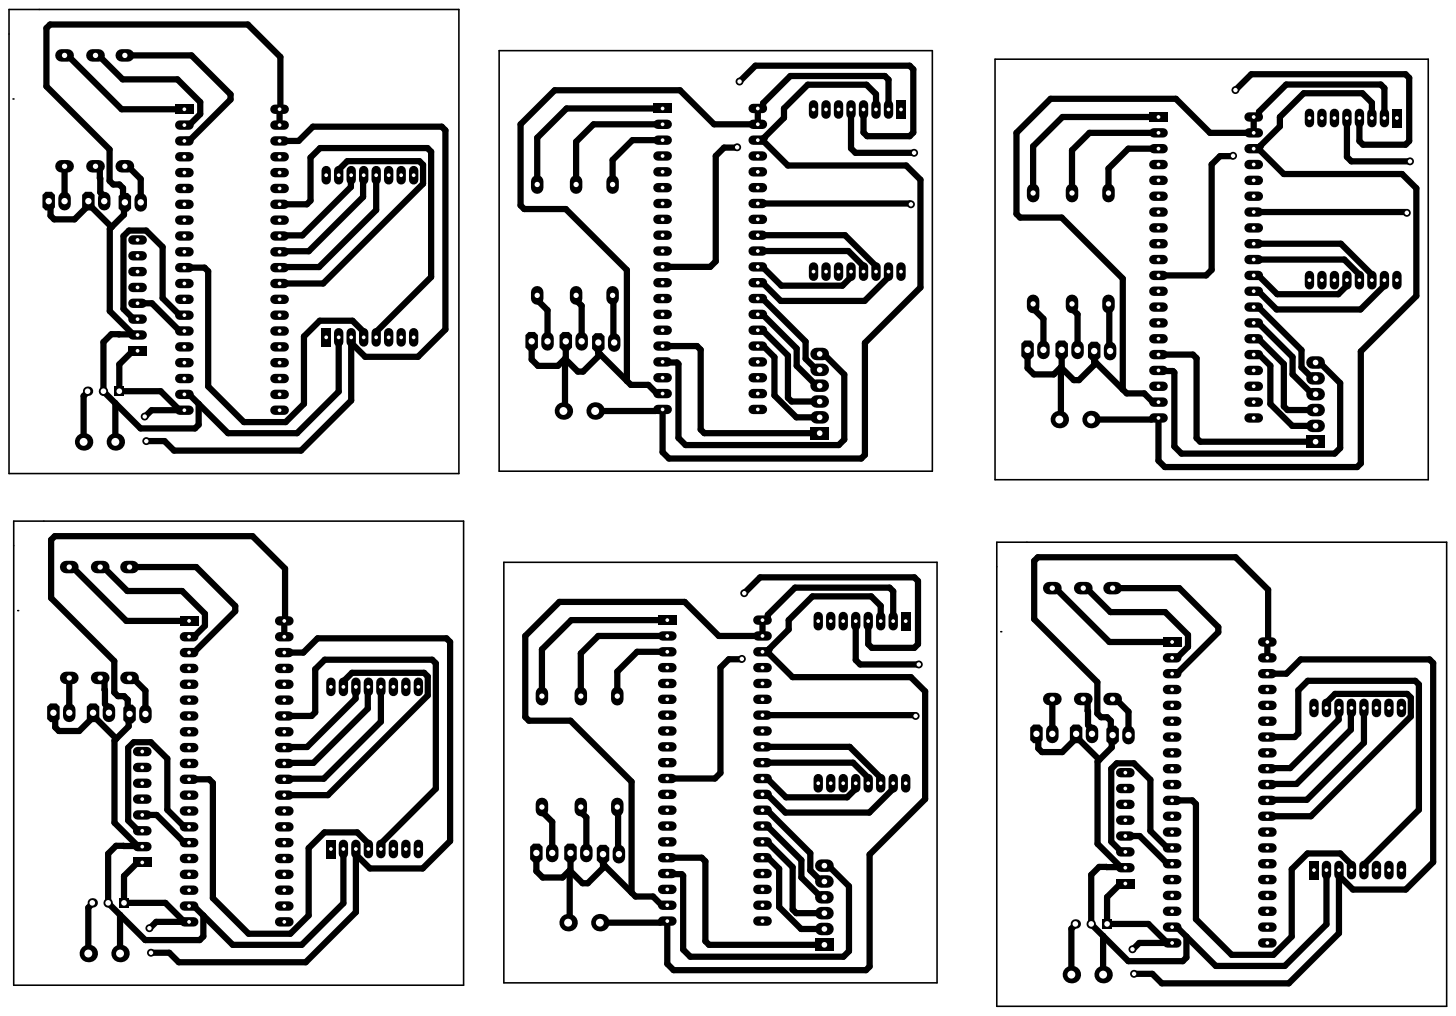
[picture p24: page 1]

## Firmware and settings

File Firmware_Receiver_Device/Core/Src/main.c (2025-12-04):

/******************************************************************************
 * File:   main.c
 * Author: Gemini AI (Dựa trên yêu cầu của người dùng)
 *
 * @brief  Chương trình chính cho xe điều khiển bằng LoRa.
 * - Nhận dữ liệu liên tục từ module LoRa RA-02.
 * - Điều khiển 2 động cơ qua driver L298N.
 * - Xe sẽ chạy theo lệnh cuối cùng nhận được cho đến khi có lệnh mới.
 *****************************************************************************/

/* Includes ------------------------------------------------------------------*/
#include "main.h"
#include "spi.h"
#include "gpio.h"
#include "tim.h"

/* USER CODE BEGIN Includes */
#include "SX1278.h"
#include "SX1278_hw.h"
#include <string.h>
/* USER CODE END Includes */

/* USER CODE BEGIN PD */
// --- Tham số LoRa (PHẢI KHỚP VỚI BÊN PHÁT) ---
#define LORA_FREQUENCY_HZ       433000000UL
#define LORA_POWER              SX1278_POWER_17DBM
#define LORA_SF                 SX1278_LORA_SF_7
#define LORA_BANDWIDTH          SX1278_LORA_BW_125KHZ
#define LORA_CODING_RATE        SX1278_LORA_CR_4_5
#define LORA_CRC_ENABLE         SX1278_LORA_CRC_EN
#define LORA_EXPLICIT_SYNCWORD  0x12
#define LORA_PACKET_LEN_CONFIG  64

// --- Định nghĩa chân điều khiển Motor L298N ---
// Motor 1 (bánh trái, điều khiển bởi ENA)
#define IN1_GPIO_Port           GPIOB
#define IN1_Pin                 GPIO_PIN_8
#define IN2_GPIO_Port           GPIOB
#define IN2_Pin                 GPIO_PIN_9
#define MOTOR1_PWM_CHANNEL      TIM_CHANNEL_1 // PA0 (nối với ENA)

// Motor 2 (bánh phải, điều khiển bởi ENB)
#define IN3_GPIO_Port           GPIOA
#define IN3_Pin                 GPIO_PIN_2
#define IN4_GPIO_Port           GPIOA
#define IN4_Pin                 GPIO_PIN_3
#define MOTOR2_PWM_CHANNEL      TIM_CHANNEL_2 // PA1 (nối với ENB)

// --- Các mức tốc độ PWM (giả sử ARR của Timer là 999) ---
#define SPEED_FULL              999
#define SPEED_RUN               200 // Tốc độ chạy tiến/lùi
#define SPEED_TURN              150 // Tốc độ khi xoay/rẽ
#define SPEED_STOP              0   // Dừng

// --- Định nghĩa chân LED báo trạng thái ---
#define LED_FORWARD_GPIO_Port   GPIOB
#define LED_FORWARD_Pin         GPIO_PIN_13
#define LED_BACKWARD_GPIO_Port  GPIOB
#define LED_BACKWARD_Pin        GPIO_PIN_14
#define LED_TURN_GPIO_Port      GPIOB
#define LED_TURN_Pin            GPIO_PIN_12
#define LED_LORA_OK_GPIO_Port   GPIOB
#define LED_LORA_OK_Pin         GPIO_PIN_12 // Dùng chung LED báo rẽ để báo LoRa OK
/* USER CODE END PD */

// Các biến này thường được CubeMX tự động tạo ra trong file tương ứng (spi.c, tim.c)
// extern SPI_HandleTypeDef hspi1;
// extern TIM_HandleTypeDef htim2;

// Biến cho chương trình LoRa và motor
SX1278_t LoRaModule_RX;
SX1278_hw_t LoRa_HW_RX;
uint8_t receivedLoRaDataBuffer[LORA_PACKET_LEN_CONFIG];
volatile uint8_t loraPacketReadyFlag_RX = 0; // Cờ báo có tín hiệu LoRa mới

void SystemClock_Config(void);

// Khai báo các hàm sẽ được định nghĩa ở cuối file
void Turn_Off_All_LEDs(void);
void Indicate_LoRa_Init_Status(int success);
void motor1_set_speed(uint16_t speed_pulse);
void motor2_set_speed(uint16_t speed_pulse);
void motor1_forward(uint16_t speed);
void motor1_backward(uint16_t speed);
void motor1_stop(void);
void motor2_forward(uint16_t speed);
void motor2_backward(uint16_t speed);
void motor2_stop(void);
void all_motors_forward(uint16_t speed);
void all_motors_backward(uint16_t speed);
void all_motors_stop(void);
void car_turn_right(uint16_t speed);
void car_turn_left(uint16_t speed);
/**
  * @brief  The application entry point.
  * @retval int
  */
int main(void)
{
  /* MCU Configuration--------------------------------------------------------*/

  /* Reset of all peripherals, Initializes the Flash interface and the Systick. */
  HAL_Init();

  /* Configure the system clock */
  SystemClock_Config();

  /* Initialize all configured peripherals */
  MX_GPIO_Init();
  MX_SPI1_Init();
  MX_TIM2_Init();
  /* USER CODE BEGIN 2 */

  Turn_Off_All_LEDs();

  // 1. Cấu hình phần cứng cho module LoRa
  LoRa_HW_RX.spi      = &hspi1;
  LoRa_HW_RX.nss.port = (void *)LORA_NSS_GPIO_Port;
  LoRa_HW_RX.nss.pin  = LORA_NSS_Pin;
  LoRa_HW_RX.reset.port = (void *)LORA_RST_GPIO_Port;
  LoRa_HW_RX.reset.pin  = LORA_RST_Pin;
  LoRa_HW_RX.dio0.port = (void *)LORA_DIO0_GPIO_Port;
  LoRa_HW_RX.dio0.pin  = LORA_DIO0_Pin;
  LoRaModule_RX.hw    = &LoRa_HW_RX;

  // 2. Khởi tạo module LoRa
  SX1278_hw_Reset(&LoRa_HW_RX);
  SX1278_init(&LoRaModule_RX,
              LORA_FREQUENCY_HZ,
              LORA_POWER,
              LORA_SF,
              LORA_BANDWIDTH,
              LORA_CODING_RATE,
              LORA_CRC_ENABLE,
              LORA_PACKET_LEN_CONFIG);

  SX1278_SPIWrite(&LoRaModule_RX, RegSyncWord, LORA_EXPLICIT_SYNCWORD);

  // 3. Kiểm tra và báo hiệu trạng thái khởi tạo LoRa
  uint8_t version = SX1278_SPIRead(&LoRaModule_RX, REG_LR_VERSION);
  Indicate_LoRa_Init_Status(version == 0x12);
  HAL_Delay(1000);
  Turn_Off_All_LEDs();

  // 4. Khởi động các kênh PWM cho động cơ
  if (HAL_TIM_PWM_Start(&htim2, MOTOR1_PWM_CHANNEL) != HAL_OK) Error_Handler();
  if (HAL_TIM_PWM_Start(&htim2, MOTOR2_PWM_CHANNEL) != HAL_OK) Error_Handler();

  // Đảm bảo động cơ dừng hoàn toàn khi bắt đầu
  all_motors_stop();

  // 5. Đặt LoRa vào chế độ nhận liên tục
  int rx_entry_status = SX1278_receive(&LoRaModule_RX, LORA_PACKET_LEN_CONFIG, SX1278_DEFAULT_TIMEOUT);
  if (!rx_entry_status)
  {
    Error_Handler();
  }
  /* USER CODE END 2 */

  /* Infinite loop */
  /* USER CODE BEGIN WHILE */
  while (1)
  {
    /* USER CODE END WHILE */

    /* USER CODE BEGIN 3 */
    // Chỉ xử lý khi có ngắt báo hiệu gói tin LoRa đã đến
    if (loraPacketReadyFlag_RX == 1)
    {
      loraPacketReadyFlag_RX = 0; // Xóa cờ ngay để chuẩn bị cho lần ngắt tiếp theo

      uint8_t bytes_in_buffer = SX1278_available(&LoRaModule_RX);

      if (bytes_in_buffer > 0)
      {
        SX1278_read(&LoRaModule_RX, receivedLoRaDataBuffer, bytes_in_buffer);
        uint8_t command = receivedLoRaDataBuffer[0]; // Lấy byte lệnh

        Turn_Off_All_LEDs(); // Tắt hết đèn cũ trước khi thực hiện lệnh mới

        // Xử lý lệnh điều khiển
        switch (command)
        {
          case 0: // Lệnh 0: Dừng xe
            all_motors_stop();
            break;

          case 1: // Lệnh 1: Rẽ phải
            car_turn_right(SPEED_TURN);
            HAL_GPIO_WritePin(LED_TURN_GPIO_Port, LED_TURN_Pin, GPIO_PIN_SET);
            break;

          case 2: // Lệnh 2: Rẽ trái
            car_turn_left(SPEED_TURN);
            HAL_GPIO_WritePin(LED_TURN_GPIO_Port, LED_TURN_Pin, GPIO_PIN_SET);
            break;

          case 3: // Lệnh 3: Chạy lùi
            all_motors_backward(SPEED_RUN);
            HAL_GPIO_WritePin(LED_BACKWARD_GPIO_Port, LED_BACKWARD_Pin, GPIO_PIN_SET);
            break;

          case 4: // Lệnh 4: Chạy tiến
            all_motors_forward(SPEED_RUN);
            HAL_GPIO_WritePin(LED_FORWARD_GPIO_Port, LED_FORWARD_Pin, GPIO_PIN_SET);
            break;

          default: // Nếu nhận lệnh lạ -> Dừng xe để đảm bảo an toàn
            all_motors_stop();
            break;
        }
      }
      // QUAN TRỌNG: Đặt lại LoRa vào chế độ nhận để sẵn sàng cho gói tin tiếp theo
      rx_entry_status = SX1278_receive(&LoRaModule_RX, LORA_PACKET_LEN_CONFIG, SX1278_DEFAULT_TIMEOUT);
      if (!rx_entry_status)
      {
        Error_Handler();
      }
    }
  }
  /* USER CODE END 3 */
}

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
/* USER CODE BEGIN 4 */

/**
  * @brief  Hàm callback được tự động gọi khi có ngắt ngoài (EXTI) xảy ra.
  * Chân DIO0 của LoRa được cấu hình để kích hoạt ngắt này khi nhận xong gói tin.
  */
void HAL_GPIO_EXTI_Callback(uint16_t GPIO_Pin)
{
  if (GPIO_Pin == LORA_DIO0_Pin)
  {
    // Đặt cờ báo hiệu cho vòng lặp chính biết rằng có dữ liệu mới
    loraPacketReadyFlag_RX = 1;
  }
}

/**
 * @brief Tắt tất cả các LED báo trạng thái của xe.
 */
void Turn_Off_All_LEDs(void)
{
  HAL_GPIO_WritePin(LED_FORWARD_GPIO_Port, LED_FORWARD_Pin, GPIO_PIN_RESET);
  HAL_GPIO_WritePin(LED_BACKWARD_GPIO_Port, LED_BACKWARD_Pin, GPIO_PIN_RESET);
  HAL_GPIO_WritePin(LED_TURN_GPIO_Port, LED_TURN_Pin, GPIO_PIN_RESET);
}

/**
 * @brief Báo hiệu trạng thái khởi tạo LoRa bằng LED.
 */
void Indicate_LoRa_Init_Status(int success)
{
  if (success)
  {
    // Khởi tạo thành công: Sáng LED
    HAL_GPIO_WritePin(LED_LORA_OK_GPIO_Port, LED_LORA_OK_Pin, GPIO_PIN_SET);
  }
  else
  {
    // Khởi tạo thất bại: Nháy LED liên tục để báo lỗi nghiêm trọng
    while (1)
    {
      HAL_GPIO_TogglePin(LED_LORA_OK_GPIO_Port, LED_LORA_OK_Pin);
      HAL_Delay(200);
    }
  }
}

// --- Các hàm điều khiển động cơ ---

void motor1_set_speed(uint16_t speed_pulse)
{
  if (speed_pulse > SPEED_FULL) speed_pulse = SPEED_FULL;
  __HAL_TIM_SET_COMPARE(&htim2, MOTOR1_PWM_CHANNEL, speed_pulse);
}

void motor2_set_speed(uint16_t speed_pulse)
{
  if (speed_pulse > SPEED_FULL) speed_pulse = SPEED_FULL;
  __HAL_TIM_SET_COMPARE(&htim2, MOTOR2_PWM_CHANNEL, speed_pulse);
}

// --- Logic điều khiển cho Motor 1 (bánh trái) ---
void motor1_forward(uint16_t speed)
{
  HAL_GPIO_WritePin(IN1_GPIO_Port, IN1_Pin, GPIO_PIN_SET);
  HAL_GPIO_WritePin(IN2_GPIO_Port, IN2_Pin, GPIO_PIN_RESET);
  motor1_set_speed(speed);
}

void motor1_backward(uint16_t speed)
{
  HAL_GPIO_WritePin(IN1_GPIO_Port, IN1_Pin, GPIO_PIN_RESET);
  HAL_GPIO_WritePin(IN2_GPIO_Port, IN2_Pin, GPIO_PIN_SET);
  motor1_set_speed(speed);
}

void motor1_stop(void)
{
  HAL_GPIO_WritePin(IN1_GPIO_Port, IN1_Pin, GPIO_PIN_RESET);
  HAL_GPIO_WritePin(IN2_GPIO_Port, IN2_Pin, GPIO_PIN_RESET);
  motor1_set_speed(SPEED_STOP);
}

// --- Logic điều khiển cho Motor 2 (bánh phải) ---
void motor2_forward(uint16_t speed)
{
  HAL_GPIO_WritePin(IN3_GPIO_Port, IN3_Pin, GPIO_PIN_SET);
  HAL_GPIO_WritePin(IN4_GPIO_Port, IN4_Pin, GPIO_PIN_RESET);
  motor2_set_speed(speed);
}

void motor2_backward(uint16_t speed)
{
  HAL_GPIO_WritePin(IN3_GPIO_Port, IN3_Pin, GPIO_PIN_RESET);
  HAL_GPIO_WritePin(IN4_GPIO_Port, IN4_Pin, GPIO_PIN_SET);
  motor2_set_speed(speed);
}

void motor2_stop(void)
{
  HAL_GPIO_WritePin(IN3_GPIO_Port, IN3_Pin, GPIO_PIN_RESET);
  HAL_GPIO_WritePin(IN4_GPIO_Port, IN4_Pin, GPIO_PIN_RESET);
  motor2_set_speed(SPEED_STOP);
}

// --- Các hàm điều khiển toàn bộ xe ---
void all_motors_forward(uint16_t speed)
{
  motor1_forward(speed);
  motor2_forward(speed);
}

void all_motors_backward(uint16_t speed)
{
  motor1_backward(speed);
  motor2_backward(speed);
}

void all_motors_stop(void)
{
  motor1_stop();
  motor2_stop();
}

void car_turn_right(uint16_t speed)
{
  // Bánh trái tiến, bánh phải lùi -> xe quay tại chỗ sang phải
  motor1_forward(speed);
  motor2_backward(speed);
}

void car_turn_left(uint16_t speed)
{
  // Bánh trái lùi, bánh phải tiến -> xe quay tại chỗ sang trái
  motor1_backward(speed);
  motor2_forward(speed);
}
/* USER CODE END 4 */
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


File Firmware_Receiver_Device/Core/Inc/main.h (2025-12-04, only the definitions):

#define IN3_Pin GPIO_PIN_2
#define IN3_GPIO_Port GPIOA
#define IN4_Pin GPIO_PIN_3
#define IN4_GPIO_Port GPIOA
#define LORA_NSS_Pin GPIO_PIN_4
#define LORA_NSS_GPIO_Port GPIOA
#define LORA_DIO0_Pin GPIO_PIN_1
#define LORA_DIO0_GPIO_Port GPIOB
#define LORA_DIO0_EXTI_IRQn EXTI1_IRQn
#define LED1_Pin GPIO_PIN_12
#define LED1_GPIO_Port GPIOB
#define LED2_Pin GPIO_PIN_13
#define LED2_GPIO_Port GPIOB
#define LED3_Pin GPIO_PIN_14
#define LED3_GPIO_Port GPIOB
#define LORA_RST_Pin GPIO_PIN_3
#define LORA_RST_GPIO_Port GPIOB
#define IN1_Pin GPIO_PIN_8
#define IN1_GPIO_Port GPIOB
#define IN2_Pin GPIO_PIN_9
#define IN2_GPIO_Port GPIOB

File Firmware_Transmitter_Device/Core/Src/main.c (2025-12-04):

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
/* Includes ------------------------------------------------------------------*/
#include "main.h"
#include "i2c.h"
#include "spi.h"
#include "gpio.h"

/* USER CODE BEGIN PTD */
typedef struct {
    int16_t Accel_X_RAW;
    int16_t Accel_Y_RAW;
    int16_t Accel_Z_RAW;
    float Ax, Ay, Az;
} MPU6050_Data_t;
/* USER CODE END PTD */

/* USER CODE BEGIN PD */

// --- MPU6050 Defines ---
#define MPU6050_I2C_ADDR        (0x68 << 1)
#define MPU6050_REG_WHO_AM_I    0x75
#define MPU6050_REG_PWR_MGMT_1  0x6B
#define MPU6050_REG_SMPLRT_DIV  0x19
#define MPU6050_REG_ACCEL_CONFIG 0x1C
#define MPU6050_REG_GYRO_CONFIG 0x1B
#define MPU6050_REG_ACCEL_XOUT_H 0x3B

// --- LED Defines ---
// LED PB12 cho trục Xoay (Roll)
#ifndef MPU_LED_X_Pin
#define MPU_LED_X_Pin           GPIO_PIN_12
#define MPU_LED_X_GPIO_Port     GPIOB
#endif
// LED PB13 cho Cúi xuống (Pitch Down)
#ifndef MPU_LED_Y_Pin
#define MPU_LED_Y_Pin           GPIO_PIN_13
#define MPU_LED_Y_GPIO_Port     GPIOB
#endif
// LED PB14 cho Ngửa lên (Pitch Up)
#ifndef MPU_LED_Z_Pin
#define MPU_LED_Z_Pin           GPIO_PIN_14
#define MPU_LED_Z_GPIO_Port     GPIOB
#endif

// LED trạng thái chung trên chân PC13
#ifndef STATUS_LED_Pin
#define STATUS_LED_Pin          GPIO_PIN_13
#define STATUS_LED_GPIO_Port    GPIOC
#endif

// --- Ngưỡng logic MPU ---
// Khi đặt trên mặt bàn (phẳng)
#define FLAT_AZ_MIN_ABS      0.85f // Gia tốc Z (tuyệt đối) phải LỚN HƠN
#define FLAT_AXY_MAX_ABS     0.30f // Gia tốc X và Y (tuyệt đối) phải NHỎ HƠN

// Khi xoay/nghiêng
#define TILT_AX_RIGHT_THRESHOLD  0.45f  // Xoay phải: Ax > ngưỡng
#define TILT_AX_LEFT_THRESHOLD  -0.45f  // Xoay trái: Ax < ngưỡng
#define TILT_AY_UP_THRESHOLD     0.45f  // Ngửa lên: Ay > ngưỡng
#define TILT_AY_DOWN_THRESHOLD  -0.45f  // Cúi xuống: Ay < ngưỡng

// Để xác định nghiêng rõ ràng, các trục khác không nên quá lớn
#define OTHER_AXES_MAX_ABS_FOR_CLEAR_TILT 0.75f

/* USER CODE END PD */


void SystemClock_Config(void);
/* USER CODE BEGIN 0 */
PUTCHAR_PROTOTYPE
{
  ITM_SendChar(ch);
  return ch;
}

// --- MPU6050 Functions Definitions ---
HAL_StatusTypeDef MPU6050_Write_Reg(uint8_t reg, uint8_t value) {
    return HAL_I2C_Mem_Write(&hi2c1, MPU6050_I2C_ADDR, reg, I2C_MEMADD_SIZE_8BIT, &value, 1, HAL_MAX_DELAY);
}
HAL_StatusTypeDef MPU6050_Read_Reg(uint8_t reg, uint8_t *data) {
    return HAL_I2C_Mem_Read(&hi2c1, MPU6050_I2C_ADDR, reg, I2C_MEMADD_SIZE_8BIT, data, 1, HAL_MAX_DELAY);
}
HAL_StatusTypeDef MPU6050_Read_Multi_Reg(uint8_t reg, uint8_t *data, uint16_t count) {
    return HAL_I2C_Mem_Read(&hi2c1, MPU6050_I2C_ADDR, reg, I2C_MEMADD_SIZE_8BIT, data, count, HAL_MAX_DELAY);
}
HAL_StatusTypeDef MPU6050_Init_Device(void) {
    uint8_t check_val; HAL_StatusTypeDef status;
    status = MPU6050_Read_Reg(MPU6050_REG_WHO_AM_I, &check_val);
    if (status != HAL_OK) return HAL_ERROR;
    if (check_val != 0x68) return HAL_ERROR;
    status = MPU6050_Write_Reg(MPU6050_REG_PWR_MGMT_1, 0x00); if (status != HAL_OK) return HAL_ERROR;
    HAL_Delay(10);
    status = MPU6050_Write_Reg(MPU6050_REG_SMPLRT_DIV, 0x07); if (status != HAL_OK) return HAL_ERROR;
    status = MPU6050_Write_Reg(MPU6050_REG_ACCEL_CONFIG, 0x00); if (status != HAL_OK) return HAL_ERROR; // +/- 2g
    status = MPU6050_Write_Reg(MPU6050_REG_GYRO_CONFIG, 0x00); if (status != HAL_OK) return HAL_ERROR;   // +/- 250 deg/s
    return HAL_OK;
}
HAL_StatusTypeDef MPU6050_Read_Accel_Raw(MPU6050_Data_t *data_struct) {
    uint8_t rec_data[6]; HAL_StatusTypeDef status;
    status = MPU6050_Read_Multi_Reg(MPU6050_REG_ACCEL_XOUT_H, rec_data, 6);
    if (status != HAL_OK) { return HAL_ERROR; }
    data_struct->Accel_X_RAW = (int16_t)(rec_data[0] << 8 | rec_data[1]);
    data_struct->Accel_Y_RAW = (int16_t)(rec_data[2] << 8 | rec_data[3]);
    data_struct->Accel_Z_RAW = (int16_t)(rec_data[4] << 8 | rec_data[5]);
    return HAL_OK;
}
void MPU6050_Convert_To_G(MPU6050_Data_t *data_struct) {
    float accel_sensitivity = 16384.0f; // Độ nhạy cho thang đo +/- 2g
    data_struct->Ax = data_struct->Accel_X_RAW / accel_sensitivity;
    data_struct->Ay = data_struct->Accel_Y_RAW / accel_sensitivity;
    data_struct->Az = data_struct->Accel_Z_RAW / accel_sensitivity;
}

// --- LED Control Functions ---
void Turn_Off_MPU_LEDs(void) {
  HAL_GPIO_WritePin(MPU_LED_X_GPIO_Port, MPU_LED_X_Pin, GPIO_PIN_RESET); // PB12
  HAL_GPIO_WritePin(MPU_LED_Y_GPIO_Port, MPU_LED_Y_Pin, GPIO_PIN_RESET); // PB13
  HAL_GPIO_WritePin(MPU_LED_Z_GPIO_Port, MPU_LED_Z_Pin, GPIO_PIN_RESET); // PB14
}

// --- Status Indication Function ---
void Indicate_Overall_Status(int status_code) {
  #ifdef STATUS_LED_Pin
  switch(status_code) {
    case 0: // Lỗi nghiêm trọng -> Nháy chậm liên tục
      while (1) {
        HAL_GPIO_TogglePin(STATUS_LED_GPIO_Port, STATUS_LED_Pin); HAL_Delay(500);
      }
      break;
    case 1: // Khởi tạo OK -> Sáng 0.5s rồi tắt
      HAL_GPIO_WritePin(STATUS_LED_GPIO_Port, STATUS_LED_Pin, GPIO_PIN_RESET); HAL_Delay(500);
      HAL_GPIO_WritePin(STATUS_LED_GPIO_Port, STATUS_LED_Pin, GPIO_PIN_SET);
      break;
    case 2: // Đang gửi TX -> Chớp nhanh 1 lần
      HAL_GPIO_WritePin(STATUS_LED_GPIO_Port, STATUS_LED_Pin, GPIO_PIN_RESET); HAL_Delay(30);
      HAL_GPIO_WritePin(STATUS_LED_GPIO_Port, STATUS_LED_Pin, GPIO_PIN_SET);
      break;
    case 3: // Gửi TX thất bại -> Chớp nhanh 3 lần
      for(int i=0; i<3; i++){ HAL_GPIO_TogglePin(STATUS_LED_GPIO_Port, STATUS_LED_Pin); HAL_Delay(80); HAL_GPIO_TogglePin(STATUS_LED_GPIO_Port, STATUS_LED_Pin); HAL_Delay(80); }
      HAL_GPIO_WritePin(STATUS_LED_GPIO_Port, STATUS_LED_Pin, GPIO_PIN_SET);
      break;
    case 4: // Đang thử lại MPU Init -> Chớp 2 lần
      for (int k = 0; k < 2; k++) { HAL_GPIO_TogglePin(STATUS_LED_GPIO_Port, STATUS_LED_Pin); HAL_Delay(120); HAL_GPIO_TogglePin(STATUS_LED_GPIO_Port, STATUS_LED_Pin); HAL_Delay(120); }
      HAL_GPIO_WritePin(STATUS_LED_GPIO_Port, STATUS_LED_Pin, GPIO_PIN_SET);
      break;
  }
  #endif
}
/* USER CODE END 0 */
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

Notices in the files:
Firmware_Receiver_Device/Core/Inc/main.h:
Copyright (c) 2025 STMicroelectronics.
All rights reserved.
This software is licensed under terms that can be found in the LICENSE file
